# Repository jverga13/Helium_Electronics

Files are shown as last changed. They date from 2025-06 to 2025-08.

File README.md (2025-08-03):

# Helium_Electroincs
This is the Repo where all the libraries and PCB Projects are accumulated.

The paper on which we are basing the majority of the electronics system is available here.

The primary difference between the MIT Paper and our project is that we will be utilizing a camera and LiDAR for navigation, and we are employing "smarter" motors with their built-in motor controllers. 

**[📄Motor Datasheet](https://sdalal1.github.io/assets/pdf/SteadyWin_GIM6010-8_Manual_rev1.pdf)**

**[📄MIT Paper](https://dspace.mit.edu/handle/1721.1/118671)**

**[📄Design Briefing Doc](https://docs.google.com/document/d/1DcKPHw8Bp2Dq9DMruZHhCCMiKNKUiSHHHZJS374k190/edit?usp=sharing)**

**[📄FAQ Document](https://docs.google.com/document/d/1BC8SMq1RszyV6IFdDRlEQbNECk61Qy4wqWS1KBNw0LQ/edit?usp=sharing)**

Images of path below.



**Electronics Logic Flow**
NotebookLM Mind Map (6)

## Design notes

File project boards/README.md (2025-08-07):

# Helium Electronics System Architecture

This directory contains the design files for the custom Printed Circuit Boards (PCBs) that form the core of the robot's electronic system. The architecture is designed to safely manage power and handle the high-speed, real-time communication necessary for dynamic locomotion. The system consists of three primary components:

- **Battery Management System (BMS)**
- **Power Supply Unit (PDB)**
- **SPIne Communication Board**

## Board Interconnection and Function

The diagram below illustrates how the boards connect to each other and to the robot's main computer and motors.

Board Interconnection Diagram

### BMS (Battery Management System)

**Function**: The BMS serves as the robot's primary power source and safety watchdog. We leverage the robust, pre-existing BMS found within a commercial cordless drill battery rather than designing this board ourselves.

**Responsibilities**:
- Provides raw, high-current 24V DC power for the entire system.
- Ensures the safety of the lithium-ion battery pack by managing:
  - Cell balancing
  - Protection against over-charge, over-discharge, short-circuits, and overheating

### PDB (Power Supply Unit)

**Function**: The PDB acts as the central power hub, taking the raw 24V from the battery's BMS and conditioning it for distribution to all other parts of the robot.

**Responsibilities**:
- Provides a high-current 24V rail to power the twelve motor actuators.
- Provides a low-current 1A 5V rail to power the LiDAR (LiDAR is connected to Jetson via Ethernet or USB).
- Includes a pre-charge circuit to safely manage the large inrush of current to the motor controllers' capacitors upon startup.
- Generates a clean, regulated 5V DC "logic power" supply that runs the SPIne board and the Jetson/UP Board (which is connected to the camera via USB).

### SPIne (Communication Board) (July31CommBrd/SPIne-master)

**Function**: The SPIne serves as the real-time "nervous system" of the robot, acting as a high-speed communication bridge between the robot's "brain" (the Jetson/UP Board) and the "muscles" (the motors).

**Responsibilities**:
- Connects to the main computer via a 40-pin header and receives high-level commands (e.g., "move leg 1") over a fast SPI bus.
- Uses two powerful STM32 microcontrollers to translate these simple commands into complex, low-level CAN bus messages.
- Manages four independent, galvanically isolated CAN networks—one for each 3-motor leg. This critical isolation protects the sensitive computer from electrical noise or voltage spikes generated by the motors.
- Maintains the high-frequency (1 kHz+) communication loop required for dynamic balancing and locomotion.

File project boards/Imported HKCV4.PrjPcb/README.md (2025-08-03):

# HKCV4 - [ARCHIVED - REFERENCE ONLY]

**⚠️ IMPORTANT NOTE FOR THE TEAM ⚠️**

This directory, `Imported HKCV4.PrjPcb`, contains the design files for the communication and interface board used in the original MIT research paper. In that project, this board served the role of the high-level computer interface, similar to how we are using a Jetson Nano or UP Board.

**We are NOT using this board in our project.**

These files are archived here for **historical and reference purposes only**. They provide context for how the SPIne and Connector boards were originally connected and controlled.

---

## Original Function (For Context)

The board documented in these files was the central communication hub in the MIT robot. Its primary function was to:

* Act as the main interface board, connecting to a computer like an UP Board.
* Receive high-level commands from the computer over an SPI bus.
* Translate these commands into CAN bus messages for the four 3-DOF legs.
* It is functionally equivalent to what the paper refers to as the **"SPIne"** board.

For our project's active development, please refer to the design files in the `July31CommBrd,` `Best_Connector_board_July`, and `PDB` directories.

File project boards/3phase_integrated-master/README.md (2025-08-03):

## 3-Phase Brushless Motor Controller (V4)

Hardware design files for the Cheetah V4 integrated motor controller.

### Status: Archived ⚠️

This design is a legacy project and is **not in active use**. We have transitioned to using motors with integrated controllers, which makes this external controller board unnecessary for current projects.

The motors we are using are the GIM6010-8-Lite 5Nm 120RPM Max 11Nm 420RPM Robot dog motor with gear box 8:1 and ODrive driver CAN/RS485 Stator 6010 388g. 

### Related Documentation
- **Target Motor Datasheet:** [SteadyWin GIM6010-8 Manual](https://sdalal1.github.io/assets/pdf/SteadyWin_GIM6010-8_Manual_rev1.pdf)
- **Quick Stats GIM Family Motors** [SMC Powers Data Sheet](http://shop.smc-powers.com/GIM6010-8-Lite-Odrive.htlm)
- **Where We Ordered The Motors From** [Amazon](https://www.amazon.com/Planetary-Robotic-Exoskeleton-Control-GIM6010-8/dp/B0DQ7N2M5X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)

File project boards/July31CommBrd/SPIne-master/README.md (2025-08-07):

## Smaller SPIne Communication Board (Cost-Reduced Version)

This directory contains the design files for a modified, cost-reduced version of the main SPIne Communication Board.

### Key Modifications
The primary goal of this version is to lower costs and simplify in-house manufacturing.

- **Reduced Size:** The PCB dimensions have been significantly decreased to lower the cost of fabrication.
- **Fit the OSH Park Rules** The PCB is changed so that it fits OSH parks rules (tracings, distance between components, other errors that occurred  when put into OSH Park Rules)

---
### Original Board Overview

This board is based on the main **SPIne Communication Board**, which acts as the central nervous system for the robot. It processes high-level commands from a host computer (like a Jetson Nano) and manages real-time communication with the motors via CAN bus. It's designed to work with a secondary Connector Board that distributes power and signals.

The core features of the original design include:
- **Dual STM32F446 Microcontrollers** for real-time processing.
- **A 40-pin header** to stack directly onto a host computer.
- **Four independent and galvanically isolated CAN bus channels** for robust motor communication.
- **Onboard power regulation** and isolated DC-DC converters.

---
### Full Documentation

For a complete breakdown of the original board's design, components, and system architecture, please see the full documentation on Notion:

**[📄FAQ Document](https://docs.google.com/document/d/1BTmc7MTexFd-CQ0lYXevFovfLc9VMLDNh9eOhk8kmDs/edit?usp=sharing)**

**[📄 Briefing Doc](https://docs.google.com/document/d/1LLA47OMKxJ5xzOaiPruQMuQE-OeMwa2zv2Psi5w3PYQ/edit?usp=sharing)**

**[📄 Helium Project - SPIne System Details](https://www.notion.so/atombot/The-Helium-Project-1a723e66a3218009b606e8f94d7b40a9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)**

**[📄 Microcontroller Choice Explanation Document](https://docs.google.com/document/d/166toBr8D5q9DAse6OPuDGO7630AuwiWQxv-KNbx1AGk/edit?usp=sharing)**

**[📄 Original Github of SPIne Board](https://github.com/bgkatz/SPIne/tree/master/SPIne_V2)**

image (5)
image (6)

**Concept Tree**

NotebookLM Mind Map (4)

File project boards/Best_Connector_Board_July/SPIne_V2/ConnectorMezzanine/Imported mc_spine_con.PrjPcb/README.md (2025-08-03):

# SPIne Connector and Power Distribution Board

This repository contains the design files for the `mc_spine_con`, a passive connector and power distribution board designed to work with the SPIne V2 communication board for dynamic legged robots.

## Overview

The purpose of this board is to serve as a robust breakout and wiring hub. It takes the bundled power and communication signals from the main SPIne board and distributes them cleanly to the robot's four legs and other peripherals like the remote control receiver and emergency stop. This simplifies the robot's wiring harness, making assembly and maintenance much easier.

This board was designed as part of the research detailed in the [MIT Masters Thesis by Benjamin G. Katz](https://dspace.mit.edu/handle/1721.1/117362).
**I have adjusted this board in the following ways to ensure can iterate on this design quickly through the use of the in-lab Carvera PCB CNC:**
- Replacing the components that are out of circulation
- Changing location of components and traces based on in-lab Carvera rules.

---

## Features

* **Central Input:** A single **20-pin male header** (`SV2`) receives all signals and power from the main SPIne board.
* **Leg Outputs:** Four **4-pin Molex Micro-Fit connectors** (`LEG1` - `LEG4`) provide dedicated power and CAN bus communication to each of the robot's four legs.
* **Remote Control:** A **3-pin header for SBUS** allows for the direct connection of a standard RC radio receiver for low-latency manual control.
* **Safety Interface:** A **2-pin header for an Emergency Stop (ESTOP)** provides a connection point for a critical safety cutoff switch.
* **Power Taps:** Five **8-pin Molex Micro-Fit headers** (`P$1`) are available for distributing power to other subsystems.
* **Mounting:** Four **mounting holes** (`MH1` - `MH4`) allow the board to be securely fastened to the robot chassis.
* **Construction:** Simple and robust **2-layer PCB** design, suitable for manufacturing with desktop PCB makers or professional fabrication houses.

---

## Repository Contents

* **/AltiumProject/**: Contains the source Altium Designer project files, including:
    * `mc_spine_con.PcbDoc` - The PCB layout file.
    * `mc_spine_con.SchDoc` - The schematic file.
* **/Gerber/**: Manufacturing files (Gerbers) for producing the PCB.
* **/BOM/**: The Bill of Materials (`.csv`) listing all required components and their part numbers.
* `README.md`: This file.

---

## Integration

This board is designed to be the interface layer between the main SPIne V2 board and the robot's hardware.

1.  The **female 20-pin connector** (`SV1`, Harwin `M20-7822046`) on the main SPIne board plugs directly into the **male 20-pin header** (`SV2`, Harwin `M20-9992046`) on this connector board.
2.  The `LEG` ports connect to the motor controllers in each leg.
3.  The `SBUS` and `ESTOP` ports connect to the respective external hardware.
4.  The main power for the system is supplied to the SPIne board, which then passes it through to this board for distribution.

---

## License

This project is licensed under the MIT License. See the `LICENSE` file for details.

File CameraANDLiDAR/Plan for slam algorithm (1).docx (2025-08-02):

### ✅ Most Relevant Tutorials

1. RGB-D Handheld Mapping
  - Why: Your RealSense D435i is an RGB-D camera, which is directly supported by this tutorial.
  - Use Case: This will help you understand how to perform SLAM using only the D435i.
2. Setup RTAB-Map on Your Robot!
  - Why: Since you’re using both an RGB-D camera and a LiDAR, this tutorial helps integrate multiple sensors.
  - Use Case: Essential if you're mounting these sensors on a robot and want to combine odometry, visual data, and LiDAR.
3. Advanced Parameter Tuning
  - Why: When combining RGB-D and LiDAR, performance tuning is important for accuracy and efficiency.
  - Use Case: Optimize SLAM performance once basic setup is complete.

### 🚧 Potentially Useful (Depending on Deployment)

4. Remote Mapping
  - Why: Useful if the compute-heavy SLAM processing is done on a separate computer.
  - Use Case: Consider this if your robot is lightweight and offloads processing.
5. Stereo Outdoor Mapping / Navigation
  - Why: Not directly applicable since you're not using stereo, but helpful if you're working in outdoor environments and want ideas on sensor fusion/navigation.
  - Use Case: You can extract concepts related to environment challenges and trajectory planning.

### ❌ Not Directly Applicable

- Stereo Handheld Mapping
- Mapping and Navigation with Turtlebot
- Tango ROS Streamer
- Wifi Signal Strength Mapping

These are either tied to specific hardware (e.g., stereo cameras, Turtlebot, Tango) or niche use cases not related to your current SLAM goal.

### Suggested Learning Path

1. Start with "RGB-D Handheld Mapping" to understand how to get RTAB-Map working with the D435i.
2. Then go to "Setup RTAB-Map on Your Robot!" to integrate LiDAR and configure multi-sensor input.
3. Use "Advanced Parameter Tuning" to refine performance and improve map quality.
4. (Optional) Use "Remote Mapping" if you're offloading compute tasks.

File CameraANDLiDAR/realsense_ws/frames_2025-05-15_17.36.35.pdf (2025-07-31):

view_frames Result

Recorded at time: 1747344995.4423993

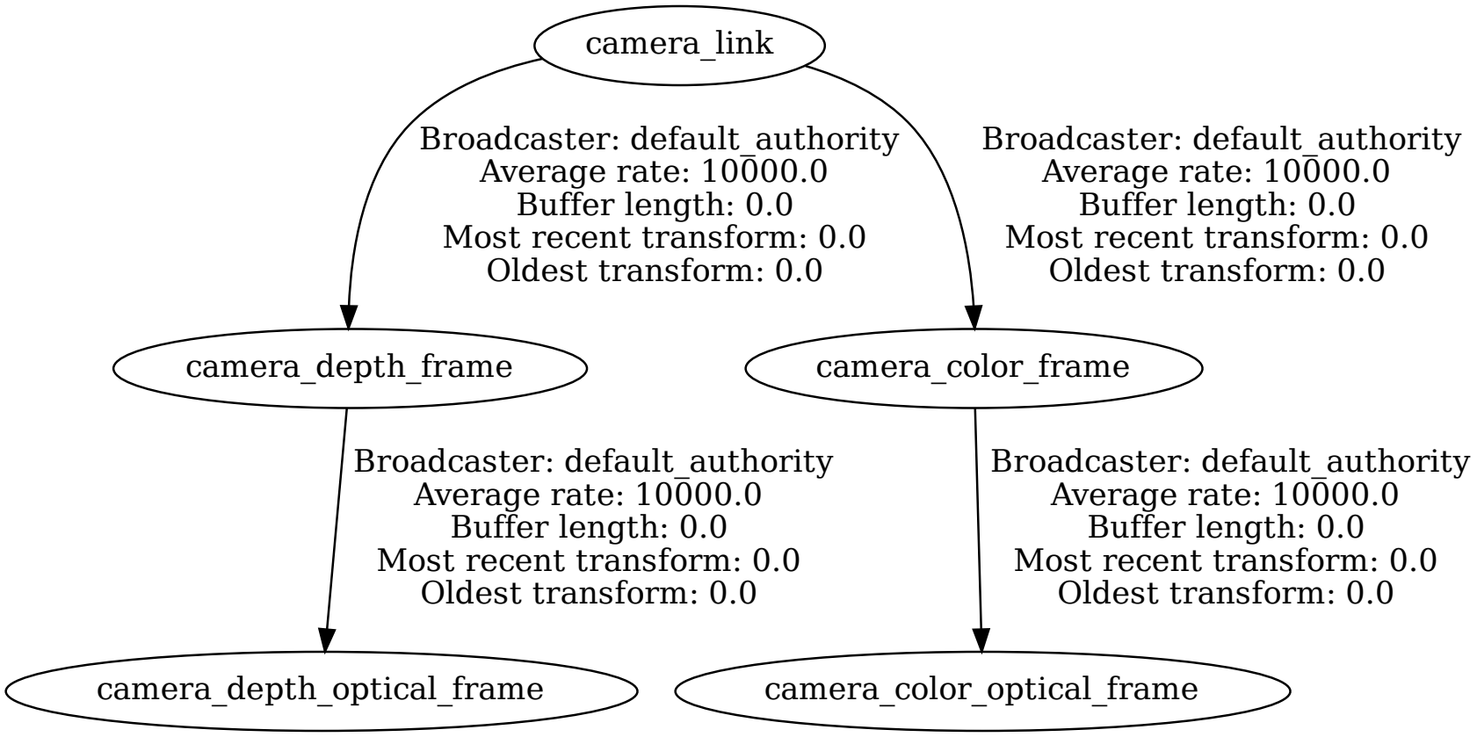
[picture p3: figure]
camera_link; camera_depth_frame; Broadcaster: default_authority Average rate: 10000.0 Buffer length: 0.0 Most recent transform: 0.0 Oldest transform: 0.0; camera_color_frame; camera_depth_optical_frame; camera_color_optical_frame

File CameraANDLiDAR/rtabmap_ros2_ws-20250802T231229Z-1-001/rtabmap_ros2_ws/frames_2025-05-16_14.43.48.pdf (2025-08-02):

view_frames Result

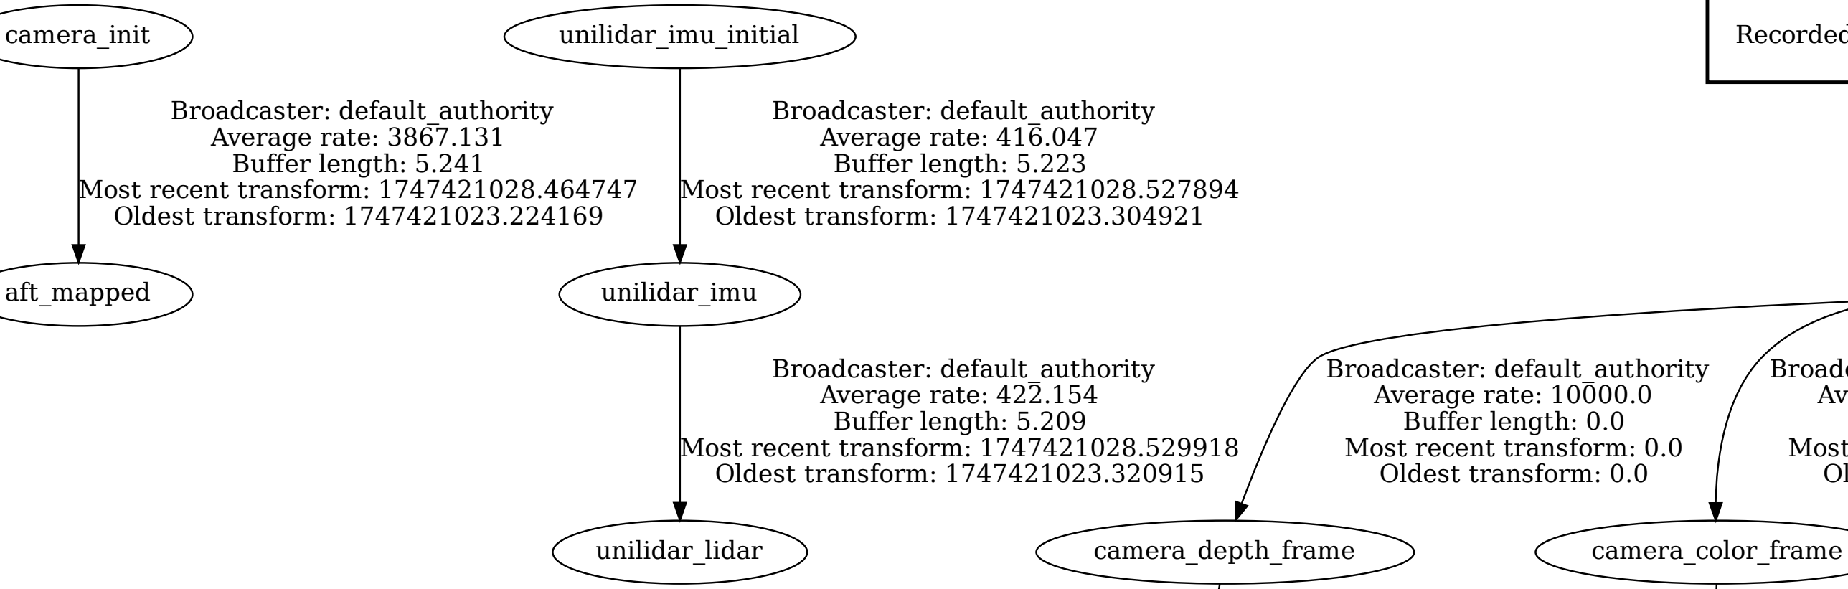
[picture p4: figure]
camera_init; aft_mapped; Broadcaster: default_authority Average rate: 3867.131 Buffer length: 5.241 Most recent transform: 1747421028.464747 Oldest transform: 1747421023.224169; unilidar_imu_initial; unilidar_imu; Broadcaster: default_authority Average rate: 416.047 Buffer length: 5.223 Most recent transform: 1747421028.527894 Oldest transform: 1747421023.304921; unilidar_lidar; Broadcaster: default_authority Average rate: 422.154 Buffer length: 5.209 Most recent transform: 1747421028.529918 Oldest transform: 1747421023.320915; camera_depth_frame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

Recorded at time: 1747421028.5395234

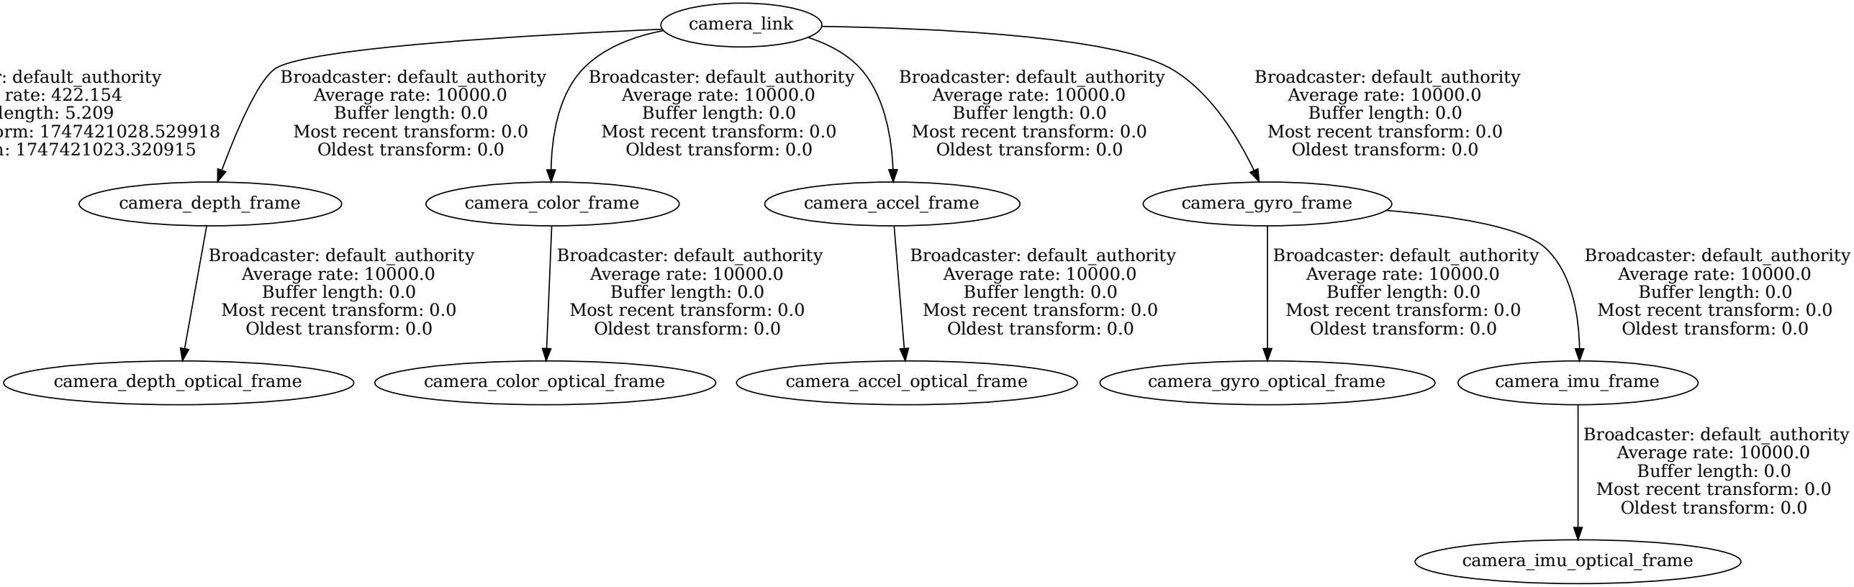
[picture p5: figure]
camera_link; Broadcaster: default_authority Average rate: 10000.0 Buffer length: 0.0 Most recent transform: 0.0 Oldest transform: 0.0; camera_accel_frame; camera_gyro_frame; camera_depth_optical_frame; camera_color_optical_frame; camera_accel_optical_frame; camera_gyro_optical_frame; camera_imu_frame; camera_imu_optical_frame

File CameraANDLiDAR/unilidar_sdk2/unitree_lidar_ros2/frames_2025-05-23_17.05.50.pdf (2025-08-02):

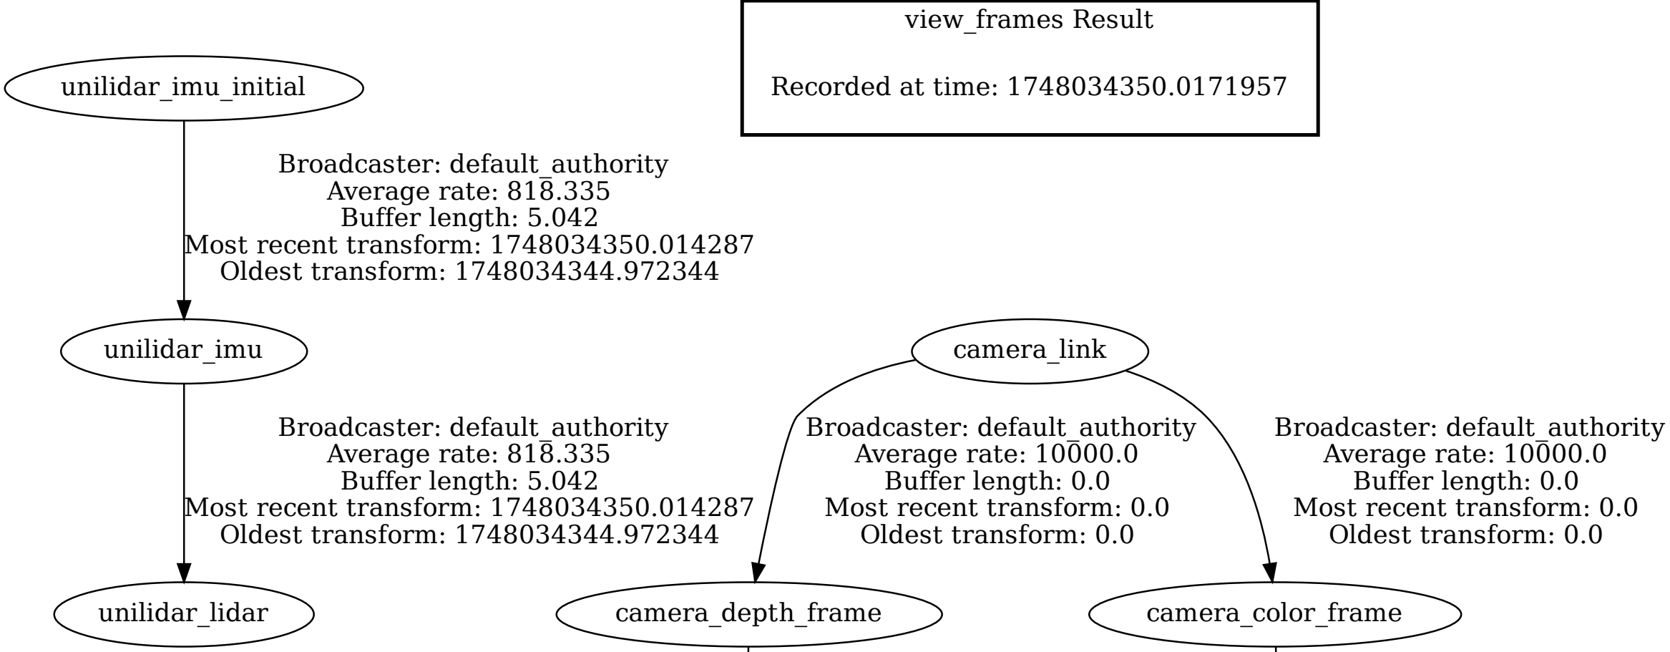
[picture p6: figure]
view_frames Result; unilidar_imu_initial; unilidar_imu; Broadcaster: default_authority Average rate: 818.335 Buffer length: 5.042 Most recent transform: 1748034350.014287 Oldest transform: 1748034344.972344; unilidar_lidar; camera_link; camera_depth_frame; Broadcaster: default_authority Average rate: 10000.0 Buffer length: 0.0 Most recent transform: 0.0 Oldest transform: 0.0; camera_color_frame; Recorded at time: 1748034350.0171957
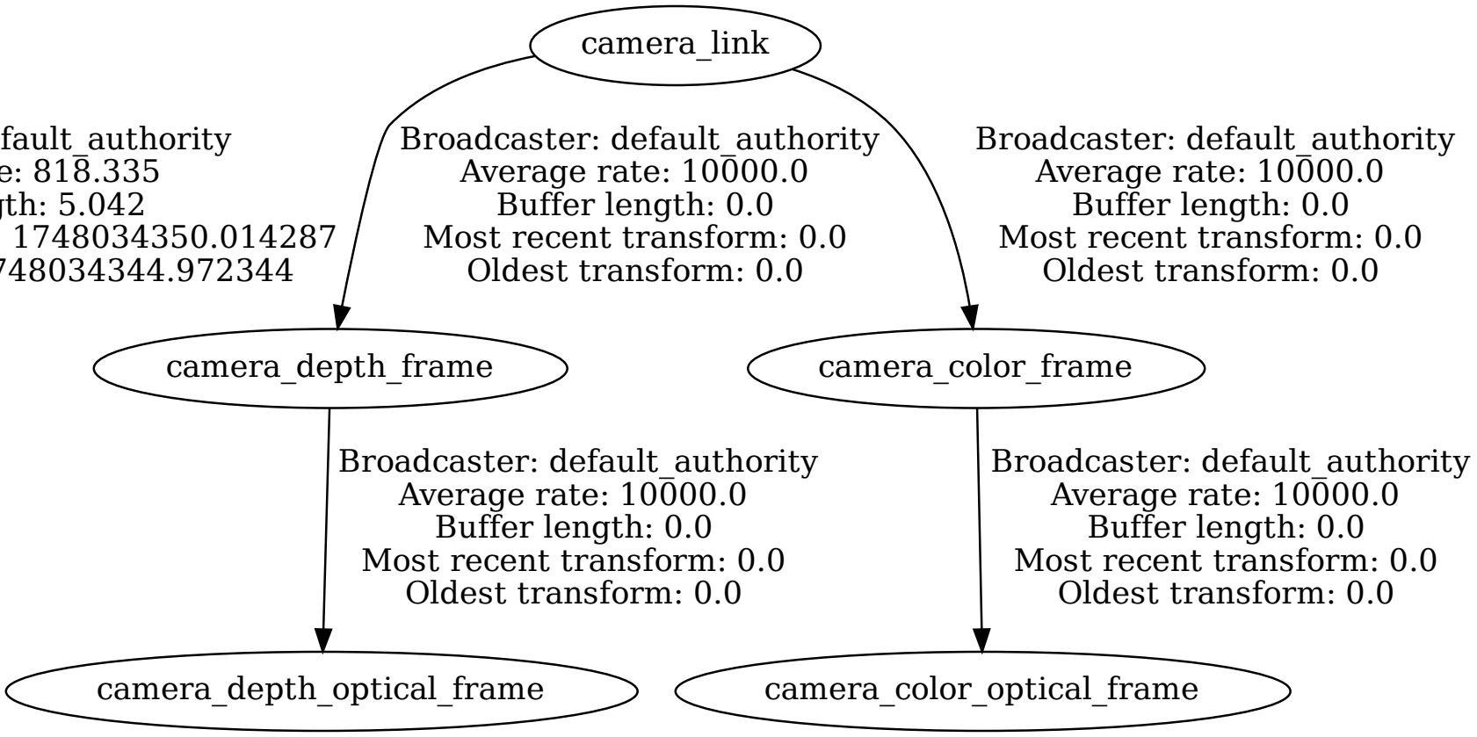
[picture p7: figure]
camera_depth_optical_frame; Broadcaster: default_authority Average rate: 10000.0 Buffer length: 0.0 Most recent transform: 0.0 Oldest transform: 0.0; camera_color_optical_frame

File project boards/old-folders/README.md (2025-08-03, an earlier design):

# [ARCHIVED] - Old and Deprecated Designs

**❗ Important Notice ❗**

This directory contains a collection of old, experimental, and deprecated design files. The contents of this folder are **not for current use**.

---

## Purpose of this Directory

The designs in this folder are kept for a few key reasons:

* **Historical Record:** They show the evolution and progression of our design process.
* **Reference:** There may be specific ideas, component footprints, or routing techniques in these old files that could be useful for reference in future projects.
* **Learning:** They serve as a record of what worked and, more importantly, what didn't.

Please **do not** use any of the projects in this directory as a starting point for new work. They may be incomplete, contain errors, or use outdated components.

For all active and current projects, please refer to the main project directories.

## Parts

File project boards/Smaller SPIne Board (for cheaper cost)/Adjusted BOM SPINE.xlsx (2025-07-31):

# of Components | Value | Package | Part | MFG Part Number | Digikey Number | Substitute Part Numbler | Function | Ordered (Y/N)
1 |  | 43045-0400 (https://www.digikey.com/en/products/detail/molex/0430450400/252527?msockid=1619689cf2a2642d35897d04f3dc6515) | DC_IN | ‎0430450400‎ | ‎WM1814-ND‎ | 430450411 (https://www.digikey.com/en/products/detail/molex/0430450411/252545) | Main DC Power Input: Receives power from the robot's primary battery.
1 |  | MA20-1L (https://www.digikey.com/en/products/detail/harwin-inc/M20-7822046/3727872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) | SV1 | ‎M20-7822046‎ | ‎952-1905-ND‎ |  | 20-pin Connector to Connector Board: Interface that passes power and communication signals to the mc_spine_con breakout board.
4 | 120 | R0402 (https://www.digikey.com/en/products/detail/te-connectivity-passive-product/CRGCQ0603F120R/8576279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) | R3, R5, R6, R7 | ‎CRGCQ0603F120R‎ | ‎A129677CT-ND‎ |  | CAN Bus Termination Resistors: 120-ohm resistors placed at the physical ends of the CAN bus to prevent signal reflections and ensure reliable communication.
1 | DNP | R0402 (https://www.digikey.com/en/products/detail/yageo/RC0402JR-070RL/726406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) | BYP | RC0402JR-070RL |  | RC0402JR-070RP (https://www.digikey.com/en/products/detail/yageo/RC0402JR-070RP/4935394) | Bypass Resistor (Do Not Populate): A placeholder on the PCB for testing or optional configurations; not installed in the final assembly. |  | <-- don't order this now
20 | .1 uF | C0603K (https://www.digikey.com/en/products/detail/kemet/C0603C104M5RACTU/2199782) | C1, C8, C12, C14, C16, C18, C19, C20, C21, C22, C23, C24, C4, C5, C6, C25, C27, C29, C31, C32 | ‎C0603C104M5RACTU‎ | ‎399-7845-1-ND‎ |  | Decoupling/Filtering Capacitors: Placed near ICs to filter high-frequency noise from power supply lines and provide a stable voltage for digital components.
8 | 1uF | C0603 (https://www.digikey.com/en/products/detail/taiyo-yuden/UMK107AB7105KA-T/3660085) | C7, C41, C11, C13, C15, C17, C3, C10 | ‎UMK107AB7105KA-T‎ | ‎587-3247-1-ND‎ |  | Decoupling/Filtering Capacitors: Mid-range frequency filtering for power stability.
1 | 10 uF | C0805K (https://www.digikey.com/en/products/detail/murata-electronics/GRM188R61E106MA73D/3900497) | C30 | ‎GRM188R61E106MA73D‎ | ‎490-7202-1-ND‎ |  | Bulk Decoupling Capacitor: Larger capacitor to handle lower-frequency fluctuations and sudden current demands from the circuit.
2 | 4.7 uF | C0603 (https://www.digikey.com/en/products/detail/samsung-electro-mechanics/CL10A475MQ8NNNC/3887565) | C2, C9 | ‎CL10A475MQ8NNNC‎ | ‎1276-1907-1-ND‎ |  | Decoupling/Filtering Capacitors: Additional filtering for power stability.
5 | 47 uF | C1206K (https://www.digikey.com/en/products/detail/murata-electronics/GRT32EC81C476KE13L/5417195) | C28, C33, C34, C35, C36 | ‎GRM32EC81C476KE15K‎ | ‎490-16309-1-ND‎ | GRT32EC81C476KE13L (https://www.digikey.com/en/products/detail/murata-electronics/GRT32EC81C476KE13L/5417195) | Bulk Decoupling Capacitors: Provides a substantial local energy reserve to stabilize voltage during large, rapid changes in current draw.
2 | 600r | 603 (https://www.digikey.com/en/products/detail/pulse-electronics/PE-0603FB601ST/5050541) | CHOKE, CHOKE1 | ‎PE-0603FB601ST‎ | ‎553-2384-1-ND‎ |  | Power Supply Filtering Chokes: Inductors that form an LC filter with capacitors to block high-frequency noise from entering sensitive parts of the circuit.
2 | 200 | R0603 (https://www.digikey.com/en/products/detail/yageo/RC0603JR-07200RL/726737) | R4, R22 | ‎RC0603JR-07200RL‎ | ‎311-200GRCT-ND‎ |  | General Purpose Resistors: Used for tasks like current limiting or as part of pull-up/pull-down circuits to ensure signals are in a defined state.
1 | 74AHC1G14DCK | SC70-5 (https://www.digikey.com/en/products/detail/texas-instruments/SN74AHC1G14DCKR/373809) | IC1 | SN74AHC1G14DCKR | 296-8748-1-ND |  | Logic Gate (Schmitt-Trigger Inverter): Inverts a digital signal and provides clean, sharp output transitions, even from noisy or slow-changing inputs.
2 | BM07B-SRSS-TB | BM07B-SRSS-TB (https://www.digikey.com/en/products/detail/jst-sales-america-inc/BM07B-SRSS-TB/926699) | PROG, PROG1 | ‎BM07B-SRSS-TB(LF)(SN)‎ | ‎455-1793-1-ND‎ |  | Programming/Debug Ports for MCUs: Allows direct connection (e.g., SWD/JTAG) for flashing firmware and real-time debugging of the microcontrollers.
2 | CSTCE | CSTCE (https://www.digikey.com/en/products/detail/murata-electronics/CSTNE8M00GH5C000R0/8747742) | XT1, XT2 | CSTNE8M00GH5C000R0‎ | ‎490-17961-1-ND‎ |  | Crystal Resonators for MCUs: Provides a precise and stable 8 MHz clock signal, which is essential for the microcontrollers to execute instructions and time communications accurately.
2 | LED_RED | LED-0603 (https://www.digikey.com/en/products/detail/liteon/LTST-C191KRKT/386837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) | LED2, LED4 | ‎LTST-C191KRKT‎ | ‎160-1447-1-ND‎ |  | Status Indicator LEDs: Provides visual feedback on the board's status, such as power on, communication activity, or error codes.
1 | LM1117 | SOT-223 (https://www.digikey.com/en/products/detail/texas-instruments/LM1117MPX-3-3-NOPB/366733) | VR1 | LM1117MPX-3.3/NOPB | LM1117MPX-3.3/NOPBCT-ND |  | 3.3V Linear Voltage Regulator: Converts the main input voltage to a stable 3.3V to power the microcontrollers and other digital logic ICs.
4 | ‎MCP2562-E/SN‎ | SO08 (https://www.digikey.com/en/products/detail/microchip-technology/MCP2562-E-SN/4079967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) | U$4, U$5, U$6, U$7 | ‎MCP2562-E/SN‎ | ‎MCP2562-E/SN-ND‎ |  | CAN Bus Transceivers: Converts logic-level signals (TX/RX) from the MCUs into the differential signals required for robust physical communication over the CAN bus.
4 | SI8621EC-B-IS | SO08 (https://www.digikey.com/en/products/detail/skyworks-solutions-inc/SI8621EC-B-IS/2623314) | U$8, U$9, U$10, U$11 | SI8621EC-B-IS | 336-2066-5-ND | ADUM121N1BRZ (https://www.digikey.com/en/products/detail/analog-devices-inc/ADUM121N1BRZ/5957960) | Digital Isolators for CAN Bus: Provides galvanic isolation to protect the sensitive MCUs from electrical noise and voltage spikes on the CAN bus network.
2 | STM32F446RET6 | TQFP64 (https://www.digikey.com/en/products/detail/stmicroelectronics/STM32F446RET6/5175962) | U$1, U$3 | ‎STM32F446RET6‎ | ‎497-15376-ND‎ |  | Main Microcontrollers: The "brains" of the board; they process commands from the host computer and manage communication with the robot's leg motors via CAN bus.
4 | ‎CRE1S0505S3C‎ | 4SIL (https://www.digikey.com/en/products/detail/murata-power-solutions-inc/CRE1S0505S3C/6056051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) | DC1, DC2, DC3, DC4 | ‎CRE1S0505S3C‎ | ‎811-3195-ND‎ | TMR 1-0511 (https://www.digikey.com/en/products/detail/traco-power/TMR-1-0511/9383368) | Isolated DC-DC Converters: Provides isolated 5V power, likely for the CAN bus transceivers, to prevent ground loops and protect the main power supply.
4 | 17mm hex standoff |  |  | ‎971170151‎ (https://www.digikey.com/en/products/detail/w%C3%BCrth-elektronik/971170151/6174643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) | ‎732-10424-ND‎ |  | Mechanical Standoff: Hardware for physically mounting the PCB and maintaining proper spacing within the robot's chassis.
4 | 11mm hex standoff |  |  | ‎M2106-2545-AL‎ (https://www.digikey.com/en/products/detail/raf-electronic-hardware/M2106-2545-AL/7681435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) | ‎1772-2024-ND‎ |  | Mechanical Standoff: Hardware for physically mounting the PCB and maintaining proper spacing within the robot's chassis.
1 | 40 pin |  |  | SSQ-120-02-T-D (https://www.digikey.com/en/products/detail/samtec-inc/SSQ-120-02-T-D/1111244) | SAM1193-20-ND |  | 40-pin Connector to Host Computer: Main data/control interface to the high-level computer (e.g., UP Board), carrying SPI, I2C, UART, and power signals.
*Can find & are available | *Can't find / aren't available | *Found a substitute
First Round Order Sheet
# of Components to Order (for backup & future boards and price for buying in bulk) | # Components needed on Board | MFG Part Number | Price | Component Type
30 | 20 | C0603K: ‎C0603C104M5RACTU‎ (https://www.digikey.com/en/products/detail/kemet/C0603C104M5RACTU/2199782) | $5.73 | Capacitor
20 | 8 | C0603: UMK107AB7105KA-T (https://www.digikey.com/en/products/detail/taiyo-yuden/UMK107AB7105KA-T/3660085) | $0.62 | Capacitor
10 | 1 | C0805K: ‎GRM188R61E106MA73D‎ (https://www.digikey.com/en/products/detail/murata-electronics/GRM188R61E106MA73D/3900497) | $1.50 | Capacitor
10 | 2 | C0603: ‎CL10A475MQ8NNNC‎ (https://www.digikey.com/en/products/detail/samsung-electro-mechanics/CL10A475MQ8NNNC/3887565) | $0.35 | Capacitor
10 | 5 | GRT32EC81C476KE13L (https://www.digikey.com/en/products/detail/murata-electronics/GRT32EC81C476KE13L/5417195) | $5.44 | Capacitor
10 | 4 | R0402: ‎CRGCQ0603F120R‎ (https://www.digikey.com/en/products/detail/te-connectivity-passive-product/CRGCQ0603F120R/8576279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) | $0.28 | Resistor
10 | 2 | 603: ‎PE-0603FB601ST‎ (https://www.digikey.com/en/products/detail/pulse-electronics/PE-0603FB601ST/5050541) | $0.33 | Inductor
10 | 2 | R0603: ‎RC0603JR-07200RL‎ (https://www.digikey.com/en/products/detail/yageo/RC0603JR-07200RL/726737) | $0.08 | Resistor
1 | 1 | MA20-1L: ‎M20-7822046‎ (https://www.digikey.com/en/products/detail/harwin-inc/M20-7822046/3727872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) | $2.20 | Connector
1 | 1 | SSQ-120-02-T-D (https://www.digikey.com/en/products/detail/samtec-inc/SSQ-120-02-T-D/1111244) | $3.91 | Connector
2 | 2 | STM32F446RET6 (https://www.digikey.com/en/products/detail/stmicroelectronics/STM32F446RET6/5175962) | $17.22 | STM

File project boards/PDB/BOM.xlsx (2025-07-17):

QTY | Value | Device | Parts | Digikey Part Number | Other Distributor
2 |  | DIODE-SMB | D4, D6 | 497-16321-1-ND
2 |  | HEADER_POS4_43045-0401 | 5V_OUT, 12V_OUT | ‎WM1814-ND‎
2 | .1uF 50V | C-USC0603K | C4, C17 | 399-7845-1-ND
4 | 100 | R-US_R0402 | R3, R11, R12, R13 | 311-100JRCT-ND
10 | 10k | R-US_R0402 | R1, R2, R4, R5, R6, R8, R9, R14, R15, R16 | 311-10.0KLRCT-ND
4 | 10uF 25v | C-USC0603K | C1, C3, C7, C8 | 490-7202-1-ND
8 | 10uF 50v | C-USC1206K | C9, C11, C12, C13, C16, C18, C19, C20 | 587-3248-1-ND
2 | 1uF 50v | C-USC0603K | C2, C6 | 587-3247-1-ND
2 | 2-PINM80_H | 2-PINM80_H | U$13, U$14 | 952-1076-5-ND
2 | 20k | R-US_R0402 | R7, R10 | 311-20.0KLRCT-ND
7 | 220uF 35v | CPOL-USE3.5-8 | C5, C10, C14, C15, C21, C22, C23 | UVY1V221MPD-ND
2 | 470nH | CPOL-USE3.5-8 | L1, L2 | 490-10596-1-ND
2 | 51 | CPOL-USE3.5-8 | R17, R18 | RHM51DCT-ND
2 | 78L12SMD | CPOL-USE3.5-8 | IC1, IC2 | ‎LM78L12ACM/NOPB-ND‎
2 | LMC7211BIM5/NOPB | LMC7211BIM5/NOPB | U3, U4 | ‎LMC7211BIM5/NOPBCT-ND‎
5 | N-FETPOWER_SO8 | N-FETPOWER_SO8 | Q1, Q2, Q3, Q4, Q5 | ‎TPW1R306PLL1QCT-ND‎
1 | PDQ30-Q24-S5-D | PDQ30-Q24-S5-D | 5v | 102-3891-ND
1 | PDQ30-Q24-S12-D | PDQ30-Q24-S12-D | 12v | 102-3892-ND
2 | 2 | RESISTOR D2PAK | R_L, R_M | ‎PWR263S-35-2R00J-ND‎
2 | QFIT |  | "+, -"
4 | XT30PW-F |  | U$3, U$8, U$9, U$10 |  | https://www.tme.com/us/en-us/details/xt30pw-f/dc-power-connectors/amass/
4 |  | DIODE-DO214AC | D1, D2, D3, D5 | ‎SMAJ12ALFCT-ND‎
2 |  | TMS6T3B1M1QE | Power Switches | 450-2071-ND
2 |  | M80-8980205 | Power Switch Connectors | 952-1182-ND

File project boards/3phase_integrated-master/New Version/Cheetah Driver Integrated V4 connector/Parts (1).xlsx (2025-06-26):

Supplied Parts
Qty Per Board | Value | Device | Package | Parts | MFG Part | 56
1 | DRV8323RH | DRV8323RH | QFN50P700X700X90-49N | U$1 | ‎DRV8323RSRGZT‎
2 | G | LED0603 | LED-0603 | LED1, LED2 | LTST-C191KRKT‎
1 | 3.3V 500 mA LDO | LDFM | DFN6-3X3 | LDFM33PUR | ‎LDFM33PUR‎
1 | MA700 | MA700 | QFN16 | U$11 | ‎MA700GQ-Z‎
1 | MCP2542 | MCP2542 | TDFN | U$6 | ‎MCP2542FDT-H/MNY‎
1 | SM07B-SRSS-TB | SM07B-SRSS-TB | SM07B-SRSS-TB | PROG | ‎SM07B-SRSS-TB(LF)(SN)‎
1 | STM32F446RET6 | STM32F446RET6 | TQFP64 | U$3 | ‎STM32F446RET6‎
6 | 60V | MOSFET | Power SO8 | Q1, Q2, Q3, Q4, Q5, Q6 | ‎TPH2R506PL,L1Q‎
9 | 10 uF 50v | C-USC1206K | C1206K | C1, C8, C11, C12, C13, C14, C15, C16, C17, C21, C22, C23, C24, C25, C26, C28, C29 | GRT31CR61H106ME01L
1 | 22uH 500 mA | SDR0302 | SDR0302 | L1 | ‎NRH3012T220MN‎
2 | 0.001 | R-US_R1210 | R1210 | R6, R7 | ‎PMR25HZPFV1L00‎
1 | 600r | INDUCTOR0603 | 603 | CHOKE | ‎PE-0603FB601ST‎
1 | 8 Mhz Ceramic Resonator | CSTCE | CSTCE | XT1 | ‎CSTNE8M00GH5L000R0‎
1 | 500 mA 60v | DIODE-SOD123 | SOD123 | D1 | ‎MBR0580S1-7‎
8 | .1 uF 10v X5R/X7R | C-USC0402K | C0402K | C18, C27, C31, C32, C33, C34, C41, VREFCAP | ‎CL05A104MP5NNNC
2 | .1 uF 50v X5R/X7R | C-USC0603K | C0603K | C2, C4 | ‎CC0603JRX7R9BB104‎
3 | 1 uF 10v X5R/X7R | C-USC0402K | C0402K | C7, C10, MC1 | ‎CL05A105MP5NNNC‎
1 | 1 uF 50v X5R/X7R | C-USC0603K | C0603K | C6 | ‎CL10A105KB8NNNC‎
4 | 10k 1% | R-US_R0402 | R0402 | R2, R3, R4 R27 | ‎RT0402DRE0710KL‎
1 | 150k 1% | R-US_R0402 | R0402 | R26 | ‎RMCF0402FT150K‎
2 | 200 5% | R-US_R0402 | R0402 | R5, R22 | ‎RC0402JR-07200RL‎
3 | 22 uF 10v X5R/X7R | C-USC0603K | C0603K | C3, C19, C20 | ‎CL10A226MPCNUBE‎
1 | 4.7 uF 10v X5R/X7R | C-USC0402K | C0402K | C9 | ‎GRM155R60J475ME87D‎
1 | 47 nF 50v X5R/X7R | C-USC0402K | C0402K | C5 | ‎CGA2B3X7R1H473M050BD‎
1 | 54.9k 1% | R-US_R0402 | R0402 | R1 | ‎RC0402FR-0754K9L‎

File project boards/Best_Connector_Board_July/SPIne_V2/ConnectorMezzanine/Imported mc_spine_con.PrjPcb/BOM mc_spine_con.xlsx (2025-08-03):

# of Components | Value | Package | Part | MFG Part Number | Digikey Number | Substitute Part Numbler | Description | Function | Ordered (Y/N)
6 |  |  |  | M80-8430342 (https://www.digikey.com/en/products/detail/harwin-inc/M80-8430342/3924159?s=N4IgTCBcDaILIA4AMBaBAWAzEz6IF0BfIA) | 952-2944-ND |  |  | Connection headers for the wires that connect to the Motors/ESTOP/SBUS
6 |  |  |  | S8111-46R | 952-1578-1-ND | S8121-46R (https://www.digikey.com/en/products/detail/harwin-inc/S8121-46R/2281824?s=N4IgTCBcDaIMoA4CMYkFoAsA2ASiAugL5A) |  | Clips for the wires that connect to the Motors/ESTOP/SBUS
1 |  | MA20-1L (https://www.digikey.com/en/products/detail/harwin-inc/M20-9992046/3727869) | SV2 | M20-9992046 (https://www.digikey.com/en/products/detail/harwin-inc/M20-9992046/3727869) | 952-1902-ND |  | SV2 | 20-pin Connector to Main SPIne Board
*Can find & are available | *Can't find / aren't available | *Found a substitute
Components Order List
# of Components to Order (for backup & future boards and price for buying in bulk) | # Components needed on Board | MFG Part Number | Price
8 | 6 | M80-8430342 (https://www.digikey.com/en/products/detail/harwin-inc/M80-8430342/3924159?s=N4IgTCBcDaILIA4AMBaBAWAzEz6IF0BfIA) | $13.50
10 | 6 | S8121-46R (https://www.digikey.com/en/products/detail/harwin-inc/S8121-46R/2281824?s=N4IgTCBcDaIMoA4CMYkFoAsA2ASiAugL5A) | $2.24
2 | 1 | M20-9992046 (https://www.digikey.com/en/products/detail/harwin-inc/M20-9992046/3727869) | $1.38

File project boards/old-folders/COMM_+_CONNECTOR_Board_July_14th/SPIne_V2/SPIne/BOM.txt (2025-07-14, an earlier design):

Partlist exported from C:/Users/ben/Documents/eagle/mini cheetah spine/mc_spine/spine.sch at 10/16/2019 5:14 PM

Qty Value         Device                 Package       Parts                                                    Description                                                                         MATERIAL MF MPN OC_FARNELL OC_NEWARK SPICEPREFIX
1                 HEADER_POS4_43045-0401 43045-0400    DC_IN                                                    Molex - Micro-Fit 3.0 Series connector,  3.00mm (0.118") pitch header, 4 positions.
1                 MA20-1L                MA20-1L       SV1                                                      PIN HEADER                                                                                          unknown    unknown
4                 R-US_R0402             R0402         R3, R5, R6, R7                                           RESISTOR, American symbol
1                 R-US_R0402             R0402         BYP                                                      RESISTOR, American symbol                                                                                                R
12  .1 uF         C-USC0603K             C0603K        C1, C8, C12, C14, C16, C18, C19, C20, C21, C22, C23, C24 CAPACITOR, American symbol
2   1 uF          C-USC0603              C0603         C7, C41                                                  CAPACITOR, American symbol
4   1 uF          C-USC0603K             C0603K        C11, C13, C15, C17                                       CAPACITOR, American symbol
8   100nF         C-USC0603              C0603         C4, C5, C6, C25, C27, C29, C31, C32                      CAPACITOR, American symbol
1   10uF          C-USC0805K             C0805K        C30                                                      CAPACITOR, American symbol
2   1uF           C-USC0603              C0603         C3, C10                                                  CAPACITOR, American symbol                                                                                                          
2   4.7           C-USC0603              C0603         C2, C9                                                   CAPACITOR, American symbol                                                                                                          
5   47 uF         C-USC1206K             C1206K        C28, C33, C34, C35, C36                                  CAPACITOR, American symbol
2   600r          INDUCTOR0603           0603          CHOKE, CHOKE1                                            Inductors                                                                                                                           
2   70            R-US_R0603             R0603         R4, R22                                                  RESISTOR, American symbol                                                                                                           
1   74AHC1G14DCK  74AHC1G14DCK           SC70-5        IC1                                                      Single Schmitt-Trigger Inverter Gate                                                                                                
2   BM07B-SRSS-TB BM07B-SRSS-TB          BM07B-SRSS-TB PROG, PROG1                                              Disconnectable Crimp style connector, 1.0mm pitch7 contacts                                                                         
2   CSTCE         CSTCE                  CSTCE         XT1, XT2                                                                                                                                                                                     
2   G             LED0603                LED-0603      LED2, LED4                                               LEDs
1   LM1117        LM1117                 SOT-223       VR1
4   MCP2561       MCP2561                SO08          U$4, U$5, U$6, U$7
4   SI8410        SI8410                 SO08          U$8, U$9, U$10, U$11
2   STM32F446RET6 STM32F446RET6          TQFP64        U$1, U$3                                                 ARM DSP Chip used on the WAV Trigger board.
1   UP_BOARD      UP_BOARD               UP_BOARD      U$2
4   VA-1224S      VA-1224S               4SIL          DC1, DC2, DC3, DC4                                       DC DC Converter Single Output, 1 Watt                                                               unknown    unknown

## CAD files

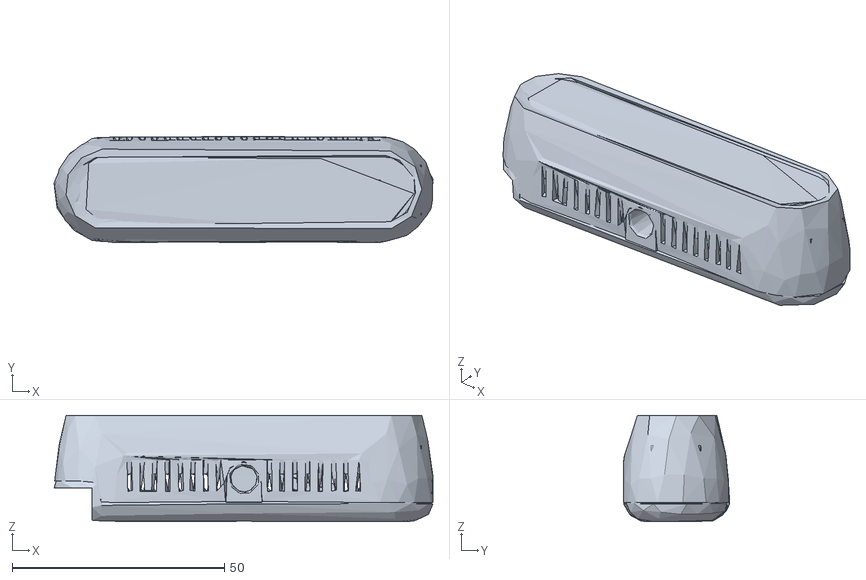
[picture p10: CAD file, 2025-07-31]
CameraANDLiDAR/tutorials-20250802T231226Z-1-001/tutorials/librealsense/common/res/sources/D435.obj
89.2 x 25.0 x 25.0

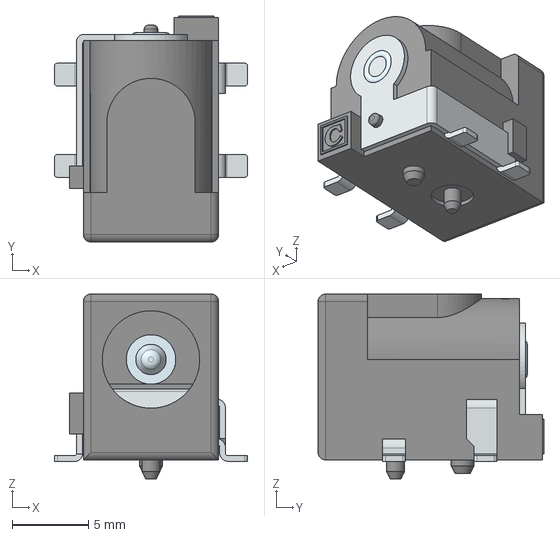
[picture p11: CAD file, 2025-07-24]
project boards/PDB/Imported PDB.PrjPcb/LiDAR power surface mount plug.stp
12.7 x 14.8 x 12.2 mm

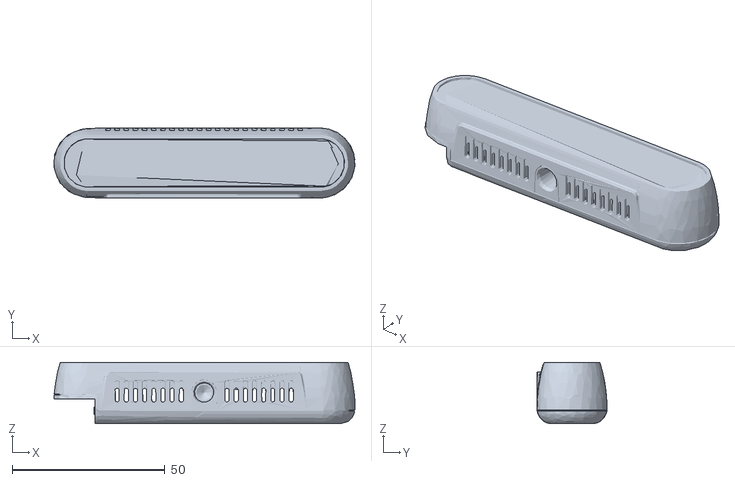
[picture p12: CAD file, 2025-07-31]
CameraANDLiDAR/tutorials-20250802T231226Z-1-001/tutorials/librealsense/common/res/sources/D415.obj
98.6 x 23.0 x 20.0

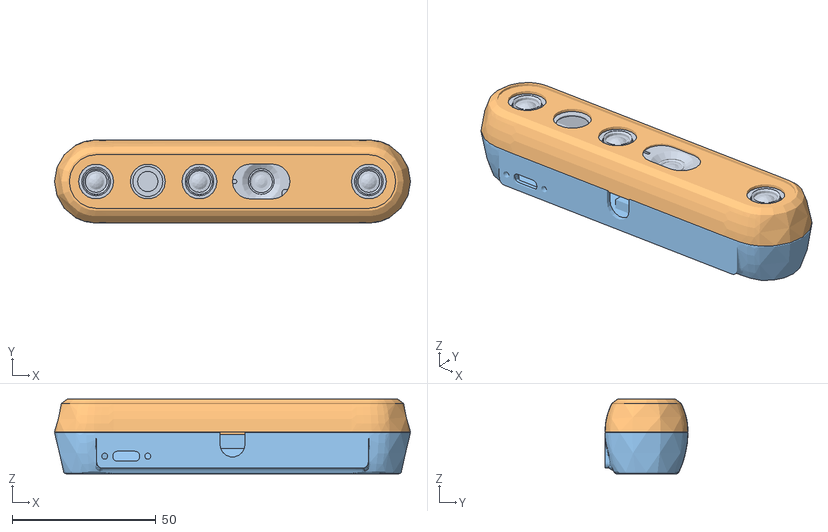
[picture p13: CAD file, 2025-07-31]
CameraANDLiDAR/tutorials-20250802T231226Z-1-001/tutorials/librealsense/common/res/sources/D455.obj
124.0 x 29.0 x 26.0

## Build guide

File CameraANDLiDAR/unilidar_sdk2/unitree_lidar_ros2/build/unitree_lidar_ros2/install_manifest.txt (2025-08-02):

/home/jverga/CameraANDLiDAR/unilidar_sdk2/unitree_lidar_ros2/install/unitree_lidar_ros2/lib/unitree_lidar_ros2/unitree_lidar_ros2_node
/home/jverga/CameraANDLiDAR/unilidar_sdk2/unitree_lidar_ros2/install/unitree_lidar_ros2/share/unitree_lidar_ros2/view.rviz
/home/jverga/CameraANDLiDAR/unilidar_sdk2/unitree_lidar_ros2/install/unitree_lidar_ros2/share/unitree_lidar_ros2/launch.py
/home/jverga/CameraANDLiDAR/unilidar_sdk2/unitree_lidar_ros2/install/unitree_lidar_ros2/share/ament_index/resource_index/package_run_dependencies/unitree_lidar_ros2
/home/jverga/CameraANDLiDAR/unilidar_sdk2/unitree_lidar_ros2/install/unitree_lidar_ros2/share/ament_index/resource_index/parent_prefix_path/unitree_lidar_ros2
/home/jverga/CameraANDLiDAR/unilidar_sdk2/unitree_lidar_ros2/install/unitree_lidar_ros2/share/unitree_lidar_ros2/environment/ament_prefix_path.sh
/home/jverga/CameraANDLiDAR/unilidar_sdk2/unitree_lidar_ros2/install/unitree_lidar_ros2/share/unitree_lidar_ros2/environment/ament_prefix_path.dsv
/home/jverga/CameraANDLiDAR/unilidar_sdk2/unitree_lidar_ros2/install/unitree_lidar_ros2/share/unitree_lidar_ros2/environment/path.sh
/home/jverga/CameraANDLiDAR/unilidar_sdk2/unitree_lidar_ros2/install/unitree_lidar_ros2/share/unitree_lidar_ros2/environment/path.dsv
/home/jverga/CameraANDLiDAR/unilidar_sdk2/unitree_lidar_ros2/install/unitree_lidar_ros2/share/unitree_lidar_ros2/local_setup.bash
/home/jverga/CameraANDLiDAR/unilidar_sdk2/unitree_lidar_ros2/install/unitree_lidar_ros2/share/unitree_lidar_ros2/local_setup.sh
/home/jverga/CameraANDLiDAR/unilidar_sdk2/unitree_lidar_ros2/install/unitree_lidar_ros2/share/unitree_lidar_ros2/local_setup.zsh
/home/jverga/CameraANDLiDAR/unilidar_sdk2/unitree_lidar_ros2/install/unitree_lidar_ros2/share/unitree_lidar_ros2/local_setup.dsv
/home/jverga/CameraANDLiDAR/unilidar_sdk2/unitree_lidar_ros2/install/unitree_lidar_ros2/share/unitree_lidar_ros2/package.dsv
/home/jverga/CameraANDLiDAR/unilidar_sdk2/unitree_lidar_ros2/install/unitree_lidar_ros2/share/ament_index/resource_index/packages/unitree_lidar_ros2
/home/jverga/CameraANDLiDAR/unilidar_sdk2/unitree_lidar_ros2/install/unitree_lidar_ros2/share/unitree_lidar_ros2/cmake/unitree_lidar_ros2Config.cmake
/home/jverga/CameraANDLiDAR/unilidar_sdk2/unitree_lidar_ros2/install/unitree_lidar_ros2/share/unitree_lidar_ros2/cmake/unitree_lidar_ros2Config-version.cmake
/home/jverga/CameraANDLiDAR/unilidar_sdk2/unitree_lidar_ros2/install/unitree_lidar_ros2/share/unitree_lidar_ros2/package.xml

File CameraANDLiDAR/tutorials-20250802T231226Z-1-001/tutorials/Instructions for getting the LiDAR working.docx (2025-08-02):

# ✅ Unitree L2 LiDAR Setup Guide for UDP over Ethernet

This guide outlines the correct procedure to configure, compile, and test Unitree L2 LiDAR in UDP mode over Ethernet using the Unitree SDK.

## 🧾 System Setup Summary

- LiDAR IP: 192.168.1.4
- PC IP: 192.168.1.3
- Serial Port: /dev/ttyACM0
- Baudrate: 4000000
- UDP Mode WorkMode: 0
- Serial Mode WorkMode: 8

## 🛠️ Edit Required Example Files (in unitree_lidar_sdk/examples)

### 1. set_to_udp_mode.cpp ✅

No changes needed. Uses:

initializeSerial("/dev/ttyACM0", 4000000);

setLidarWorkMode(0); // UDP

### 2. set_to_serial_mode.cpp ❌

Update IPs:

std::string lidar_ip = "192.168.1.4";

std::string local_ip = "192.168.1.3";

### 3. set_ip_address.cpp ❌

- Replace UDP init with Serial:

lreader->initializeSerial("/dev/ttyACM0", 4000000);

- Update IP config:

config.lidar_ip = {192, 168, 1, 4};

config.user_ip = {192, 168, 1, 3};

### 4. example_lidar_udp.cpp ✅

Already correct:

lidar_ip = "192.168.1.4";

local_ip = "192.168.1.3";

workMode = 0;

### 5. example_lidar_serial.cpp ✅

Already correct:

initializeSerial("/dev/ttyACM0", 4000000);

workMode = 8;

## 🔧 Build Instructions

cd ~/unilidar_sdk2/unitree_lidar_sdk/build

cmake ..

make -j4

## 🔁 Configuration and Execution Sequence

### 1. Set IP Address Over Serial

../bin/set_ip_address

Expect:

Unilidar initialization succeed!

Lidar IP is reset! Please reboot lidar!

### 2. Power Cycle the LiDAR

Unplug and replug the LiDAR power. Wait 10 seconds.

### 3. Set to UDP Mode

../bin/set_to_udp_mode

### 4. Configure Network on PC

sudo ip addr add 192.168.1.3/24 dev enp0s31f6

sudo ip link set dev enp0s31f6 up

### 5. Ping the LiDAR

ping 192.168.1.4

Expect 0% packet loss.

### 6. Test UDP Communication

../bin/example_lidar_udp

Expect to see live data streaming.

## 🚀 ROS2 Node Launch Setup

### launch.py Parameter Block (must match exactly):

parameters=[

{'initialize_type': 2},

{'work_mode': 0},

{'use_system_timestamp': True},

{'range_min': 0.0},

{'range_max': 100.0},

{'cloud_scan_num': 18},

{'lidar_ip': '192.168.1.4'},

{'local_ip': '192.168.1.3'},

{'lidar_port': 6101},

{'local_port': 6201},

{'cloud_frame': 'unilidar_lidar'},

{'cloud_topic': 'unilidar/cloud'},

{'imu_frame': 'unilidar_imu'},

{'imu_topic': 'unilidar/imu'},

]

❗ Remove any serial_port or baudrate entries unless using serial mode.

### ✅ Support both Serial and UDP (Optional Dynamic Setup)

Instead of hardcoding, use:

use_udp = True

params = [

{'initialize_type': 2 if use_udp else 1},

{'work_mode': 0 if use_udp else 8},

{'use_system_timestamp': True},

{'range_min': 0.0},

{'range_max': 100.0},

{'cloud_scan_num': 18},

]

if use_udp:

params += [

{'lidar_ip': '192.168.1.4'},

{'local_ip': '192.168.1.3'},

{'lidar_port': 6101},

{'local_port': 6201},

]

else:

params += [

{'serial_port': '/dev/ttyACM0'},

{'baudrate': 4000000},

]

### 🔧 Fix ROS2 Node Name Bug

In unitree_lidar_ros2.h, update:

: Node("unitree_lidar_ros2_node", options)

This name must match name='unitree_lidar_ros2_node' in launch.py.

If it's incorrect (like unitre_lidar_sdk_node), parameters won't be passed.

### 🔧 Pass NodeOptions in Main

In unitree_lidar_ros2_node.cpp, ensure:

rclcpp::spin(std::make_shared<UnitreeLidarSDKNode>(options));

## ✅ Confirm Success

- ping 192.168.1.4 works
- ../bin/example_lidar_udp streams data
- ros2 topic echo /unilidar/cloud shows point cloud
- RViz displays /unilidar/cloud with frame unilidar_lidar

You’re done! 🎉

Let me know if you want to automate this whole setup with a shell script.

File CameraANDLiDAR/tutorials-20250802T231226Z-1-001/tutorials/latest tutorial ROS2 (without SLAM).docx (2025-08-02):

# ✅ Unitree L2 LiDAR Setup Guide for UDP over Ethernet

This guide outlines the correct procedure to configure, compile, and test Unitree L2 LiDAR in UDP mode over Ethernet using the Unitree SDK and ROS2.

## 🧾 System Setup Summary

- LiDAR IP: 192.168.1.4
- PC IP: 192.168.1.3
- Serial Port: /dev/ttyACM0
- Baudrate: 4000000
- UDP Mode WorkMode: 0
- Serial Mode WorkMode: 8

## 🧰 Initial One-Time Setup (First-Time Users)

### 1. Clone and Build the SDK and ROS2 Package

mkdir -p ~/unilidar_sdk2 && cd ~/unilidar_sdk2

git clone https://github.com/unitreerobotics/unilidar_sdk2.git

cd unilidar_sdk2/unitree_lidar_sdk

mkdir build && cd build

cmake ..

make -j4

### 2. Verify and Edit Example Files (in unitree_lidar_sdk/examples)

See section "Edit Required Example Files" below to apply the necessary edits.

### 3. Set LiDAR IP Address over Serial

cd ~/unilidar_sdk2/unitree_lidar_sdk/build

../bin/set_ip_address

Reboot the LiDAR after this step.

### 4. Set the LiDAR to UDP Mode

../bin/set_to_udp_mode

### 5. Configure PC Ethernet Interface

sudo ip addr add 192.168.1.3/24 dev enp0s31f6

sudo ip link set dev enp0s31f6 up

//sudo ip addr add 192.168.1.3/24 dev eth0

### 6. Test Ping and UDP Example

ping 192.168.1.4

../bin/example_lidar_udp

### 7. Build ROS2 Package

cd ~/unilidar_sdk2/unitree_lidar_ros2

colcon build --packages-select unitree_lidar_ros2

source install/setup.bash

## 🚀 Daily Use Instructions (After Initial Setup)

Follow these steps each time you boot the computer and want to use the LiDAR:

# Set PC Ethernet IP (if not persistent)

sudo ip addr add 192.168.1.3/24 dev enp0s31f6

sudo ip link set dev enp0s31f6 up

# Ping to confirm LiDAR connectivity

ping 192.168.1.4

# Source and run ROS2 node

cd ~/unilidar_sdk2/unitree_lidar_ros2

source install/setup.bash

ros2 launch unitree_lidar_ros2 launch.py

# In another terminal (optional):

ros2 topic echo /unilidar/cloud

## 🛠️ Edit Required Example Files (in unitree_lidar_sdk/examples)

### 1. set_to_udp_mode.cpp ✅

No changes needed:

initializeSerial("/dev/ttyACM0", 4000000);

setLidarWorkMode(0); // UDP

### 2. set_to_serial_mode.cpp ❌

Update IPs:

std::string lidar_ip = "192.168.1.4";

std::string local_ip = "192.168.1.3";

### 3. set_ip_address.cpp ❌

- Replace UDP init with Serial:

lreader->initializeSerial("/dev/ttyACM0", 4000000);

- Update IP config:

config.lidar_ip = {192, 168, 1, 4};

config.user_ip = {192, 168, 1, 3};

### 4. example_lidar_udp.cpp ✅

Already correct:

lidar_ip = "192.168.1.4";

local_ip = "192.168.1.3";

workMode = 0;

### 5. example_lidar_serial.cpp ✅

Already correct:

initializeSerial("/dev/ttyACM0", 4000000);

workMode = 8;

## 🔧 Build Instructions

cd ~/unilidar_sdk2/unitree_lidar_sdk/build

cmake ..

make -j4

## 🧩 ROS2 Launch Setup

### launch.py Parameter Block

parameters=[

{'initialize_type': 2},

{'work_mode': 0},

{'use_system_timestamp': True},

{'range_min': 0.0},

{'range_max': 100.0},

{'cloud_scan_num': 18},

{'lidar_ip': '192.168.1.4'},

{'local_ip': '192.168.1.3'},

{'lidar_port': 6101},

{'local_port': 6201},

{'cloud_frame': 'unilidar_lidar'},

{'cloud_topic': 'unilidar/cloud'},

{'imu_frame': 'unilidar_imu'},

{'imu_topic': 'unilidar/imu'},

]

❗ Remove serial_port or baudrate unless using serial mode.

### ✅ Optional Dual-Mode Setup

use_udp = True

params = [

{'initialize_type': 2 if use_udp else 1},

{'work_mode': 0 if use_udp else 8},

{'use_system_timestamp': True},

{'range_min': 0.0},

{'range_max': 100.0},

{'cloud_scan_num': 18},

]

if use_udp:

params += [

{'lidar_ip': '192.168.1.4'},

{'local_ip': '192.168.1.3'},

{'lidar_port': 6101},

{'local_port': 6201},

]

else:

params += [

{'serial_port': '/dev/ttyACM0'},

{'baudrate': 4000000},

]

### 🔧 Fix ROS2 Node Name Bug

In unitree_lidar_ros2.h, update:

: Node("unitree_lidar_ros2_node", options)

### 🔧 Pass NodeOptions in Main

In unitree_lidar_ros2_node.cpp:

rclcpp::spin(std::make_shared<UnitreeLidarSDKNode>(options));

## ✅ Confirm Success

- ping 192.168.1.4 returns packets
- ../bin/example_lidar_udp shows live stream
- ros2 topic echo /unilidar/cloud outputs point cloud data
- RViz displays /unilidar/cloud with frame unilidar_lidar

You’re done! 🎉

Let me know if you want to automate this whole setup with a shell script.

c

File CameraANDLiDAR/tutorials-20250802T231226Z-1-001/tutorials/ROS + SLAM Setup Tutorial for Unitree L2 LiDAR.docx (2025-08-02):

# ROS + SLAM Setup Tutorial for Unitree L2 LiDAR

## Overview

This guide walks you step-by-step through setting up your environment, configuring the Unitree L2 LiDAR, and running SLAM using ROS Noetic and Point-LIO. It assumes zero prior experience with ROS or LiDAR systems.

## 📦 Requirements

- Ubuntu 20.04 (preferably on a physical machine or bridged VM)
- ROS Noetic
- Unitree L2 LiDAR
- Internet connection for package installation

## 🛠️ 1. Environment Setup

### 1.1 Install ROS Noetic

sudo apt update

sudo apt install curl gnupg lsb-release

sudo sh -c 'echo "deb http://packages.ros.org/ros/ubuntu $(lsb_release -sc) main" > /etc/apt/sources.list.d/ros-latest.list'

curl -s https://raw.githubusercontent.com/ros/rosdistro/master/ros.asc | sudo apt-key add -

sudo apt update

sudo apt install ros-noetic-desktop-full

### 1.2 Initialize ROS

echo "source /opt/ros/noetic/setup.bash" >> ~/.bashrc

source ~/.bashrc

sudo apt install python3-rosdep python3-rosinstall python3-rosinstall-generator python3-wstool build-essential

sudo rosdep init

rosdep update

### 1.3 Install PCL and Eigen

sudo apt install libpcl-dev libeigen3-dev

## 🌐 2. Network Configuration

### 2.1 Configure Ethernet

Connect the Unitree L2 LiDAR to your PC using Ethernet (directly or via a switch).

### 2.2 Assign Static IP to PC

Find your Ethernet interface:

ip addr

Example output shows enp0s8. Then:

sudo ip addr add 192.168.1.3/24 dev enp0s8

### 2.3 Confirm LiDAR is Reachable

ping 192.168.1.4

Expected result: replies from 192.168.1.4

## 📁 3. Clone Required Repositories

### 3.1 Create workspace

mkdir -p ~/unilidar_sdk2 && cd ~/unilidar_sdk2

git clone https://github.com/unitreerobotics/unilidar_sdk2.git

### 3.2 Build SDK Examples

cd unilidar_sdk2/unitree_lidar_sdk

mkdir build && cd build

cmake .. && make -j4

### 3.3 Set LiDAR to UDP Mode

cd ../bin

./set_to_udp_mode

./set_ip_address

Then reboot the LiDAR.

## 🤖 4. Build and Launch ROS Driver

### 4.1 Build the ROS Package

cd ~/unilidar_sdk2/unilidar_sdk2/unitree_lidar_ros

catkin_make

source devel/setup.bash

### 4.2 Update Config

Edit src/unitree_lidar_ros/config/config.yaml:

initialize_type: 2 # UDP

lidar_ip: "192.168.1.4"

pc_ip: "192.168.1.3"

### 4.3 Run Driver

roslaunch unitree_lidar_ros run_without_rviz.launch

Leave this terminal running.

## 🧭 5. Run Point-LIO SLAM

### 5.1 Build Point-LIO

cd ~/unilidar_sdk2/unilidar_sdk2/unitree_lidar_ros

mkdir -p catkin_point_lio_unilidar/src && cd catkin_point_lio_unilidar/src

git clone https://github.com/unitreerobotics/point_lio_unilidar.git

cd ..

catkin_make

roslaunch unitree_lidar_ros run_without_rviz.launch

### 5.2 Launch Mapping

roslaunch point_lio_unilidar mapping_unilidar_l2.launch

### 5.3 View Results

rviz

- Add topic: /pointlio/laser_map
- Fixed Frame: camera_init

## 🗂️ 6. Save and View Map

After you’ve finished mapping:

pcl_viewer ~/unilidar_sdk2/.../scans.pcd

(Adjust path based on your actual workspace)

## 📌 Troubleshooting

### No PointCloud in RViz?

- Run:

rostopic hz /unilidar/cloud

- Confirm it’s publishing at ~12 Hz

### LiDAR Not Pinging?

sudo ip addr add 192.168.1.3/24 dev enp0s8

ping 192.168.1.4

### Port Busy?

sudo lsof -i :6201

## ✅ Summary Checklist

## 🙋 Need Help?

Post issues to: https://github.com/unitreerobotics/unilidar_sdk2/issues

Created by: Atombot SLAM Team Lead (2025)

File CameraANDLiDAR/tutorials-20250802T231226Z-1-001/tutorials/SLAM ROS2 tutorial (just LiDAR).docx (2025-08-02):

# Full Tutorial: Running Point-LIO SLAM on Unitree L2 LiDAR with ROS2

## Overview

This guide walks you step-by-step through setting up and running Point-LIO SLAM with the Unitree L2 LiDAR in ROS2 (Humble). It assumes zero prior ROS2 experience.

## 🧠 Prerequisites

### Hardware

- A computer running Ubuntu 22.04 LTS
- Unitree L2 LiDAR
- Ethernet port or adapter

### Software

- ROS2 Humble
- Git
- colcon
- pcl-tools

## 🔧 Step 1: Install ROS2 Humble

Follow the official guide: (https://docs.ros.org/en/humble/Installation/Ubuntu-Install-Debians.html)https://docs.ros.org/en/humble/Installation/Ubuntu-Install-Debians.html

Once done:

source /opt/ros/humble/setup.bash

Add it to your ~/.bashrc:

echo "source /opt/ros/humble/setup.bash" >> ~/.bashrc

source ~/.bashrc

## 🧱 Step 2: Install Dependencies

sudo apt update

sudo apt install -y \

ros-humble-pcl-ros \

ros-humble-pcl-conversions \

ros-humble-visualization-msgs \

libeigen3-dev \

pcl-tools \

python3-colcon-common-extensions \

build-essential \

git

## 📦 Step 3: Clone and Build the Unitree L2 ROS2 Driver

git clone https://github.com/unitreerobotics/unilidar_sdk2.git

cd unilidar_sdk2/unitree_lidar_ros2

colcon build

source install/setup.bash

Add this to ~/.bashrc:

echo "source ~/unilidar_sdk2/unitree_lidar_ros2/install/setup.bash" >> ~/.bashrc

## 🔁 Step 4: Set Up LiDAR Ethernet Communication

### Assign Static IP (computer)

sudo ip addr add 192.168.1.3/24 dev <YOUR_ETH_DEVICE>

Find your Ethernet device name via:

ip addr

It may look like enp0s31f6 or enxa0cec88d4989.

### Set LiDAR IP (only once or when resetting)

cd ~/unilidar_sdk2/unitree_lidar_sdk/build

../bin/set_ip_address # sets IP to 192.168.1.4

../bin/set_to_udp_mode

Now reboot the LiDAR:

- Unplug power
- Wait 15 sec
- Plug back in
- Wait 20+ sec

### Test ping:

ping 192.168.1.4

If it replies, you're connected!

## 🧠 Step 5: Clone and Build Point-LIO (ROS2)

cd ~/unilidar_sdk2/unitree_lidar_ros2

mkdir catkin_point_lio_unilidar && cd catkin_point_lio_unilidar

mkdir src && cd src

# Clone Point-LIO with Unitree support

git clone https://github.com/dfloreaa/point_lio_ros2.git

cd ..

colcon build --symlink-install

source install/setup.bash

Add to ~/.bashrc:

echo "source ~/unilidar_sdk2/unitree_lidar_ros2/catkin_point_lio_unilidar/install/setup.bash" >> ~/.bashrc

## 🧾 Step 6: Edit the YAML Config File

Edit unilidar_l2.yaml inside point_lio/config/.

Ensure these key parameters are set:

lid_topic: "/unilidar/cloud"

imu_topic: "/unilidar/imu"

mapping:

imu_en: true

extrinsic_est_en: false

extrinsic_T: [0.007698, 0.014655, -0.00667]

extrinsic_R: [1.0, 0.0, 0.0,

0.0, 1.0, 0.0,

0.0, 0.0, 1.0]

gravity: [0.0, 0.0, -9.810]

## 🚀 Step 7: Enable Map Saving (Optional but Recommended)

In mapping_unilidar_l2.launch.py, locate laser_mapping_params and append:

'pcd_save_en': True,

'pcd_save_interval': -1

## ▶️ Step 8: Run SLAM

### Terminal 1: Start Unitree Driver

cd ~/unilidar_sdk2/unitree_lidar_ros2

source install/setup.bash

ros2 launch unitree_lidar_ros2 launch.py

### Terminal 2: Start Point-LIO

cd ~/unilidar_sdk2/unitree_lidar_ros2/catkin_point_lio_unilidar

source install/setup.bash

ros2 launch point_lio mapping_unilidar_l2.launch.py

Walk around slowly. After 5–10 seconds, you'll see points accumulate in RViz.

## 💾 Step 9: View Saved Map

Once done, stop with Ctrl+C. The map will be saved to:

~/unilidar_sdk2/unitree_lidar_ros2/catkin_point_lio_unilidar/PCD/scans.pcd

View it with:

pcl_viewer ~/unilidar_sdk2/unitree_lidar_ros2/catkin_point_lio_unilidar/PCD/scans.pcd

Use keys 1–5 in the viewer to change visualization styles.

## 🧼 Optional Cleanup

To prevent IP conflicts, remove duplicate static assignments:

sudo ip addr del 192.168.1.3/24 dev <any_wrong_interface>

## ✅ Troubleshooting

Problem | Solution
Cannot ping LiDAR | Ensure Ethernet IP is set to 192.168.1.3 and LiDAR is rebooted
RViz shows blank | Wait longer, confirm topics /cloud_registered or /Laser_map are live
No scans saved | Ensure 'pcd_save_en': True is in your launch file
pcl_viewer not found | Install: sudo apt install pcl-tools

## 🎉 Done!

You now have a working Point-LIO SLAM system with the Unitree L2. You can use the .pcd file for 3D reconstruction, analysis, or navigation experiments.

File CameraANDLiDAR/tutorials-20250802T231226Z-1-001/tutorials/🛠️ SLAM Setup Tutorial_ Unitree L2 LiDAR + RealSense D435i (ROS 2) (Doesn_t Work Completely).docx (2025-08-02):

# 🛠️ SLAM Setup Tutorial: Unitree L2 LiDAR + RealSense D435i (ROS 2)

This guide documents every step to replicate a working SLAM setup that combines:

- 3D LiDAR data from Unitree L2
- IMU + RGBD data from Intel RealSense D435i
- Odometry fusion via a custom ROS 2 node

Designed for beginners and advanced users alike.

## 🔧 System Requirements

- Ubuntu 20.04
- ROS 2 Humble installed
- Internet access for cloning packages
- USB 3.0 port for RealSense
- Ethernet for Unitree L2

## 📁 Workspace Setup

bash

CopyEdit

mkdir -p ~/combined_ros2_ws/src

cd ~/combined_ros2_ws/src

## 🔌 Step 1: LiDAR Setup

### 1. Clone the Unitree L2 ROS2 driver

bash

CopyEdit

git clone https://github.com/unitreerobotics/unilidar_sdk2.git

### 2. Configure LiDAR to UDP mode

bash

CopyEdit

cd /unilidar_sdk2/unitree_lidar_sdk/examples

./set_to_udp_mode

./set_ip_address

Make sure your LiDAR IP is set to 192.168.1.4 and your PC to 192.168.1.3.

## 📷 Step 2: RealSense Camera Setup

bash

CopyEdit

cd ~/combined_ros2_ws/src

git clone -b ros2-master https://github.com/IntelRealSense/realsense-ros.git

You will primarily use:

- /camera/camera/imu
- /camera/camera/depth/color/points

To launch:

bash

CopyEdit

source /opt/ros/humble/setup.bash

ros2 launch realsense2_camera rs_launch.py pointcloud.enable:=true enable_gyro:=true enable_accel:=true unite_imu_method:=2

## 🧠 Step 3: Point-LIO SLAM for LiDAR

bash

CopyEdit

cd ~/combined_ros2_ws/src

git clone https://github.com/dfloreaa/point_lio_ros2.git

Then:

bash

CopyEdit

cd ~/combined_ros2_ws

rosdep install --from-paths src --ignore-src -r -y

colcon build --symlink-install

source install/setup.bash

To launch Point-LIO SLAM:

bash

CopyEdit

ros2 launch point_lio mapping_unilidar_l2.launch.py

## 📦 Step 4: Odometry Fusion Node

### 1. Create Package

bash

CopyEdit

cd ~/combined_ros2_ws/src

ros2 pkg create --build-type ament_python odometry_fusion

### 2. Add Node File

Create: ~/combined_ros2_ws/src/odometry_fusion/odometry_fusion/odometry_fusion_node.py

python

CopyEdit

import rclpy

from rclpy.node import Node

from nav_msgs.msg import Odometry

from sensor_msgs.msg import Imu

class OdometryFusionNode(Node):

def __init__(self):

super().__init__('odometry_fusion_node')

self.sub_odom = self.create_subscription(Odometry, '/odom_lidar', self.odom_callback, 10)

self.sub_imu = self.create_subscription(Imu, '/imu_camera', self.imu_callback, 10)

self.pub_fused = self.create_publisher(Odometry, '/fused_odometry', 10)

self.latest_odom = None

self.latest_imu = None

def odom_callback(self, msg):

self.latest_odom = msg

self.publish_fused()

def imu_callback(self, msg):

self.latest_imu = msg

self.publish_fused()

def publish_fused(self):

if self.latest_odom and self.latest_imu:

fused = self.latest_odom

fused.header.stamp = self.latest_imu.header.stamp

fused.twist.twist.angular = self.latest_imu.angular_velocity

fused.twist.twist.linear = self.latest_odom.twist.twist.linear

self.pub_fused.publish(fused)

def main():

rclpy.init()

node = OdometryFusionNode()

rclpy.spin(node)

node.destroy_node()

rclpy.shutdown()

if __name__ == '__main__':

main()

### 3. Update setup.py

python

CopyEdit

entry_points={

'console_scripts': [

'odometry_fusion_node = odometry_fusion.odometry_fusion_node:main'

],

}

### 4. Add Launch File

Create: ~/combined_ros2_ws/src/odometry_fusion/launch/odometry_fusion_launch.py

python

CopyEdit

from launch import LaunchDescription

from launch_ros.actions import Node

def generate_launch_description():

return LaunchDescription([

Node(

package='odometry_fusion',

executable='odometry_fusion_node',

name='odometry_fusion_node',

output='screen',

remappings=[

('/odom_lidar', '/Odometry'),

('/imu_camera', '/camera/camera/imu'),

('/fused_odom', '/fused_odometry')

]

)

])

### 5. Build the Workspace

bash

CopyEdit

cd ~/combined_ros2_ws

colcon build --symlink-install

source install/setup.bash

## 🧪 Step 5: Run All Nodes in Separate Terminals

- Terminal 1: LiDAR ROS2 driver

bash

CopyEdit

ros2 launch unitree_lidar_ros2 launch.py

- Terminal 2: RealSense camera

bash

CopyEdit

ros2 launch realsense2_camera rs_launch.py pointcloud.enable:=true enable_gyro:=true enable_accel:=true unite_imu_method:=2

- Terminal 3: Point-LIO SLAM

bash

CopyEdit

ros2 launch point_lio mapping_unilidar_l2.launch.py

- Terminal 4: Odometry fusion

bash

CopyEdit

ros2 launch odometry_fusion odometry_fusion_launch.py

- Terminal 5: RViz2 to visualize /fused_odometry and /unilidar/cloud

bash

CopyEdit

rviz2

Set:

- Fixed Frame: camera_link
- Add:
  - PointCloud2 (topic: /unilidar/cloud)
  - Odometry (topic: /fused_odometry)

## ✅ Verification

Run:

bash

CopyEdit

ros2 topic echo /fused_odometry

ros2 run tf2_tools view_frames

You should see the fused odometry stream and a connected TF tree with camera_link, unilidar_lidar, and aft_mapped.

## 📄 Downloadable Version

A downloadable README.md file is provided below:

👉 Download README.md

Let me know if you want this turned into a PDF, hosted on GitHub, or converted into a step-by-step bash script.

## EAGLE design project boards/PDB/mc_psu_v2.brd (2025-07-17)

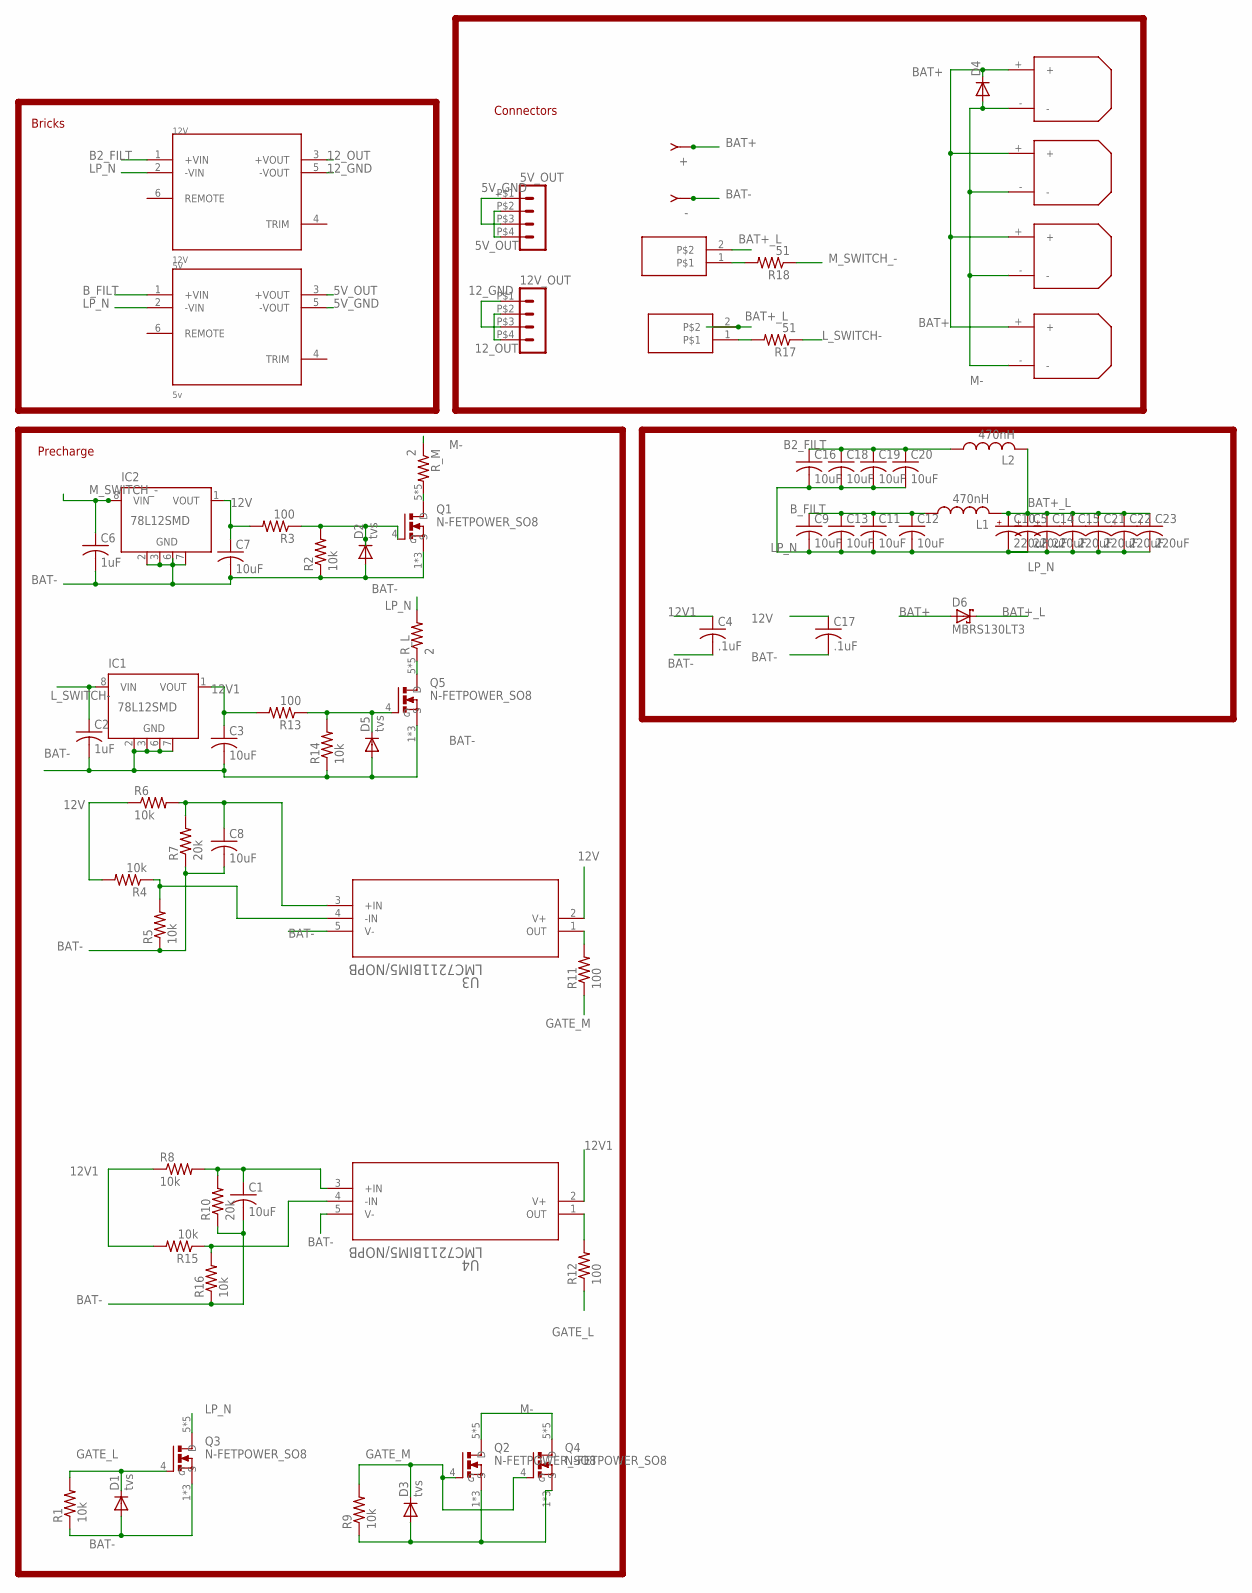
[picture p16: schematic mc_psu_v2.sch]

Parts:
5V: 5v; CONV_PDQ30-Q24-S5-D
5V_OUT, 12V_OUT: HEADER_POS4_43045-0401; 43045-0400
12V: 12V; CONV_PDQ30-Q24-S5-D
+: QFIT; FASTON
-: QFIT; FASTON
C1, C3, C7, C8: 10uF; C0603K
C2, C6: 1uF; C0603K
C4, C17: .1uF; C0603K
C5, C10, C14, C15, C21, C22, C23: 220uF; E3,5-8
C9, C11, C12, C13, C16, C18, C19, C20: 10uF; C1206K
D1, D2, D3, D5: tvs; DO214AC
D4: DIODE-SMB; SMB
D6: MBRS130LT3; SMB
IC1, IC2: 78L12SMD; SO08
L1, L2: 470nH; L3225P
Q1, Q2, Q3, Q4, Q5: N-FETPOWER_SO8; TRANS_TPH5900CNH,L1Q
R1, R2, R4, R5, R6, R8, R9, R14, R15, R16: 10k; R0402
R3, R11, R12, R13: 100; R0402
R7, R10: 20k; R0402
R17, R18: 51; R0603
R_L: 2; D2PAK
R_M: 2; D2PAK
U3, U4: LMC7211BIM5/NOPB; MF05A
U$3, U$8, U$9, U$10: XT30FEMALW; XT30_H_F
U$13, U$14: 2-PINM80_H; M80-840242

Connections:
5V_GND: 5V.5 (-VOUT), 5V_OUT.P$1 (1), 5V_OUT.P$3 (3)
5V_OUT: 5V.3 (+VOUT), 5V_OUT.P$2 (2), 5V_OUT.P$4 (4)
12V: C7.1, C17.1, IC2.1 (VOUT), R3.2, R4.2, R6.1, U3.2 (V+)
12V1: C3.1, C4.1, IC1.1 (VOUT), R8.1, R13.2, R15.2, U4.2 (V+)
12_GND: 12V.5 (-VOUT), 12V_OUT.P$1 (1), 12V_OUT.P$3 (3)
12_OUT: 12V.3 (+VOUT), 12V_OUT.P$2 (2), 12V_OUT.P$4 (4)
B2_FILT: 12V.1 (+VIN), C16.1, C18.1, C19.1, C20.1, L2.1
BAT+: +.1, +.2, D4.C, D6.A, U$3.+, U$8.+, U$9.+, U$10.+
BAT+_L: C5.+, C10.+, C14.+, C15.+, C21.+, C22.+, C23.+, D6.C, L1.2, L2.2, U$13.2, U$14.2
BAT-: -.1, -.2, C1.2, C2.2, C3.2, C4.2, C6.2, C7.2, C8.2, C17.2, D1.A, D2.A, D3.A, D5.A, IC1.2 (GND), IC1.3 (GND), IC1.6 (GND), IC1.7 (GND), IC2.2 (GND), IC2.3 (GND), IC2.6 (GND), IC2.7 (GND), Q1.1 (S), Q1.2 (S), Q1.3 (S), Q2.1 (S), Q2.2 (S), Q2.3 (S), Q3.1 (S), Q3.2 (S), Q3.3 (S), Q4.1 (S), Q4.2 (S), Q4.3 (S), Q5.1 (S), Q5.2 (S), Q5.3 (S), R1.1, R2.1, R5.1, R7.1, R9.1, R10.1, R14.1, R16.1, U3.5 (V-), U4.5 (V-)
B_FILT: 5V.1 (+VIN), C9.1, C11.1, C12.1, C13.1, L1.1
GATE_L: D1.C, Q3.4 (G), R1.2, R12.1
GATE_M: D3.C, Q2.4 (G), Q4.4 (G), R9.2, R11.1
LP_N: 5V.2 (-VIN), 12V.2 (-VIN), C5.-, C9.2, C10.-, C11.2, C12.2, C13.2, C14.-, C15.-, C16.2, C18.2, C19.2, C20.2, C21.-, C22.-, C23.-, Q3.5 (D), Q3.6 (D), Q3.7 (D), Q3.8 (D), Q3.EP (D), R_L.3 (2)
L_SWITCH-: C2.1, IC1.8 (VIN), R17.1
M-: D4.A, Q2.5 (D), Q2.6 (D), Q2.7 (D), Q2.8 (D), Q2.EP (D), Q4.5 (D), Q4.6 (D), Q4.7 (D), Q4.8 (D), Q4.EP (D), R_M.1, U$3.-, U$8.-, U$9.-, U$10.-
M_SWITCH_-: C6.1, IC2.8 (VIN), R18.1
unnamed: Q1.5 (D), Q1.6 (D), Q1.7 (D), Q1.8 (D), Q1.EP (D), R_M.3 (2)
unnamed: D5.C, Q5.4 (G), R13.1, R14.2
unnamed: D2.C, Q1.4 (G), R2.2, R3.1
unnamed: R12.2, U4.1 (OUT)
unnamed: R18.2, U$13.1
unnamed: C1.1, R8.2, R10.2, U4.3 (+IN)
unnamed: C8.1, R6.2, R7.2, U3.3 (+IN)
unnamed: R17.2, U$14.1
unnamed: R11.2, U3.1 (OUT)
unnamed: R4.1, R5.2, U3.4 (-IN)
unnamed: Q5.5 (D), Q5.6 (D), Q5.7 (D), Q5.8 (D), Q5.EP (D), R_L.1
unnamed: R15.1, R16.2, U4.4 (-IN)

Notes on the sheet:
Bricks
Precharge
Connectors

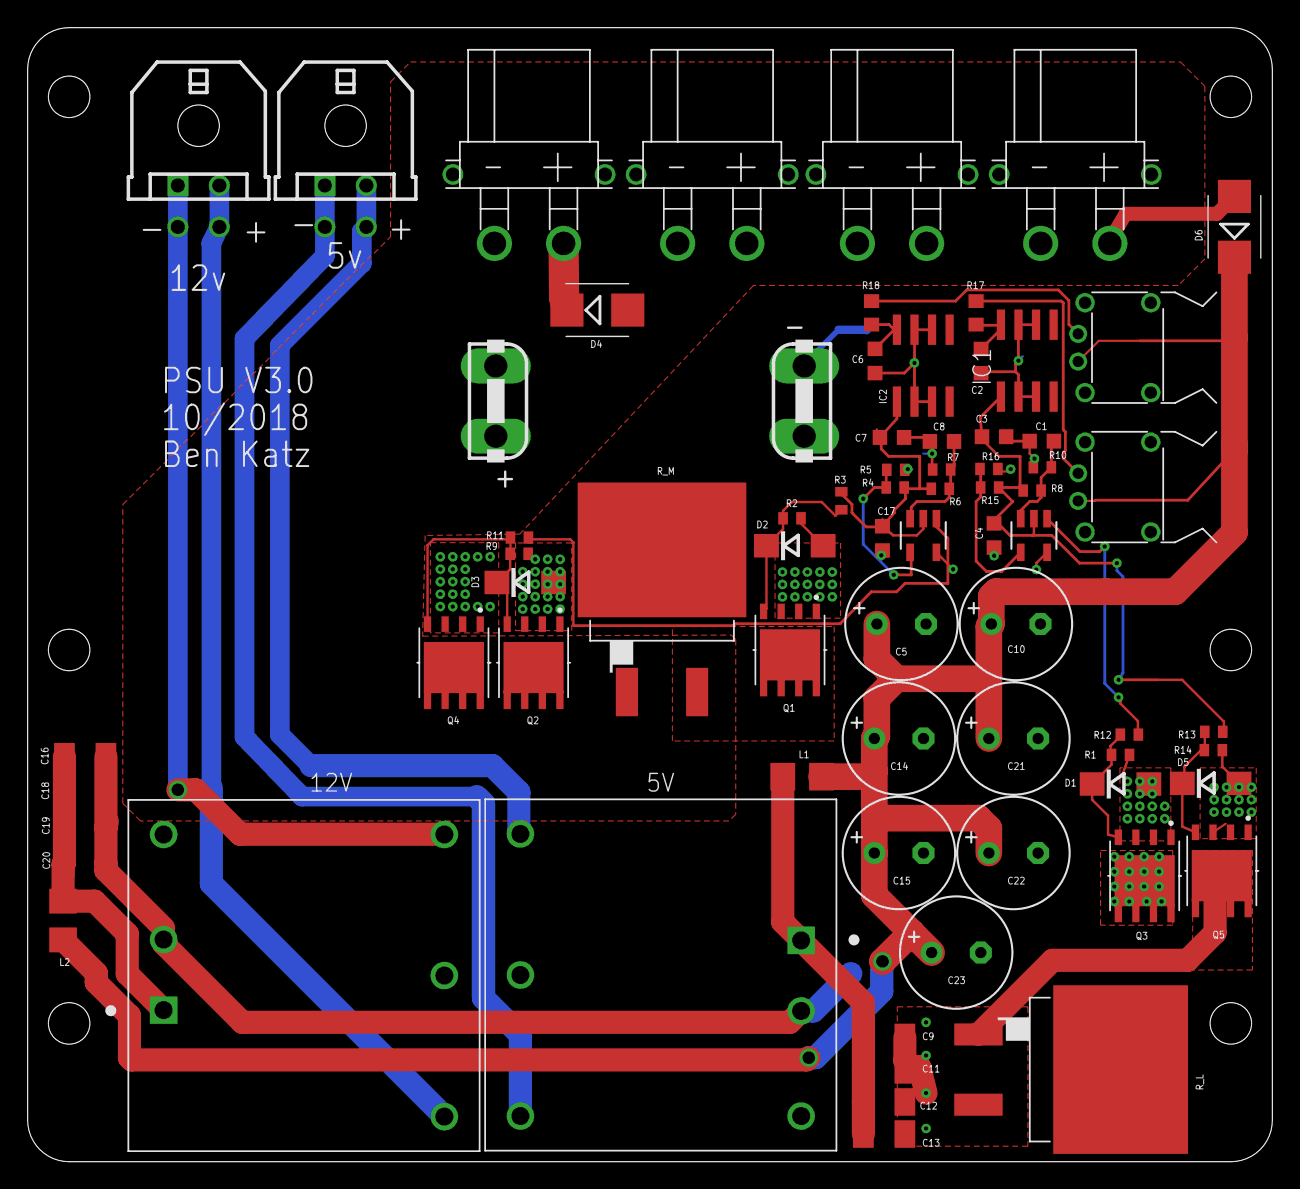
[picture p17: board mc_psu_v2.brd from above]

Board: 2 copper layers, 90.0 x 82.0 mm, 72 parts (0 on the bottom side), 29 nets.

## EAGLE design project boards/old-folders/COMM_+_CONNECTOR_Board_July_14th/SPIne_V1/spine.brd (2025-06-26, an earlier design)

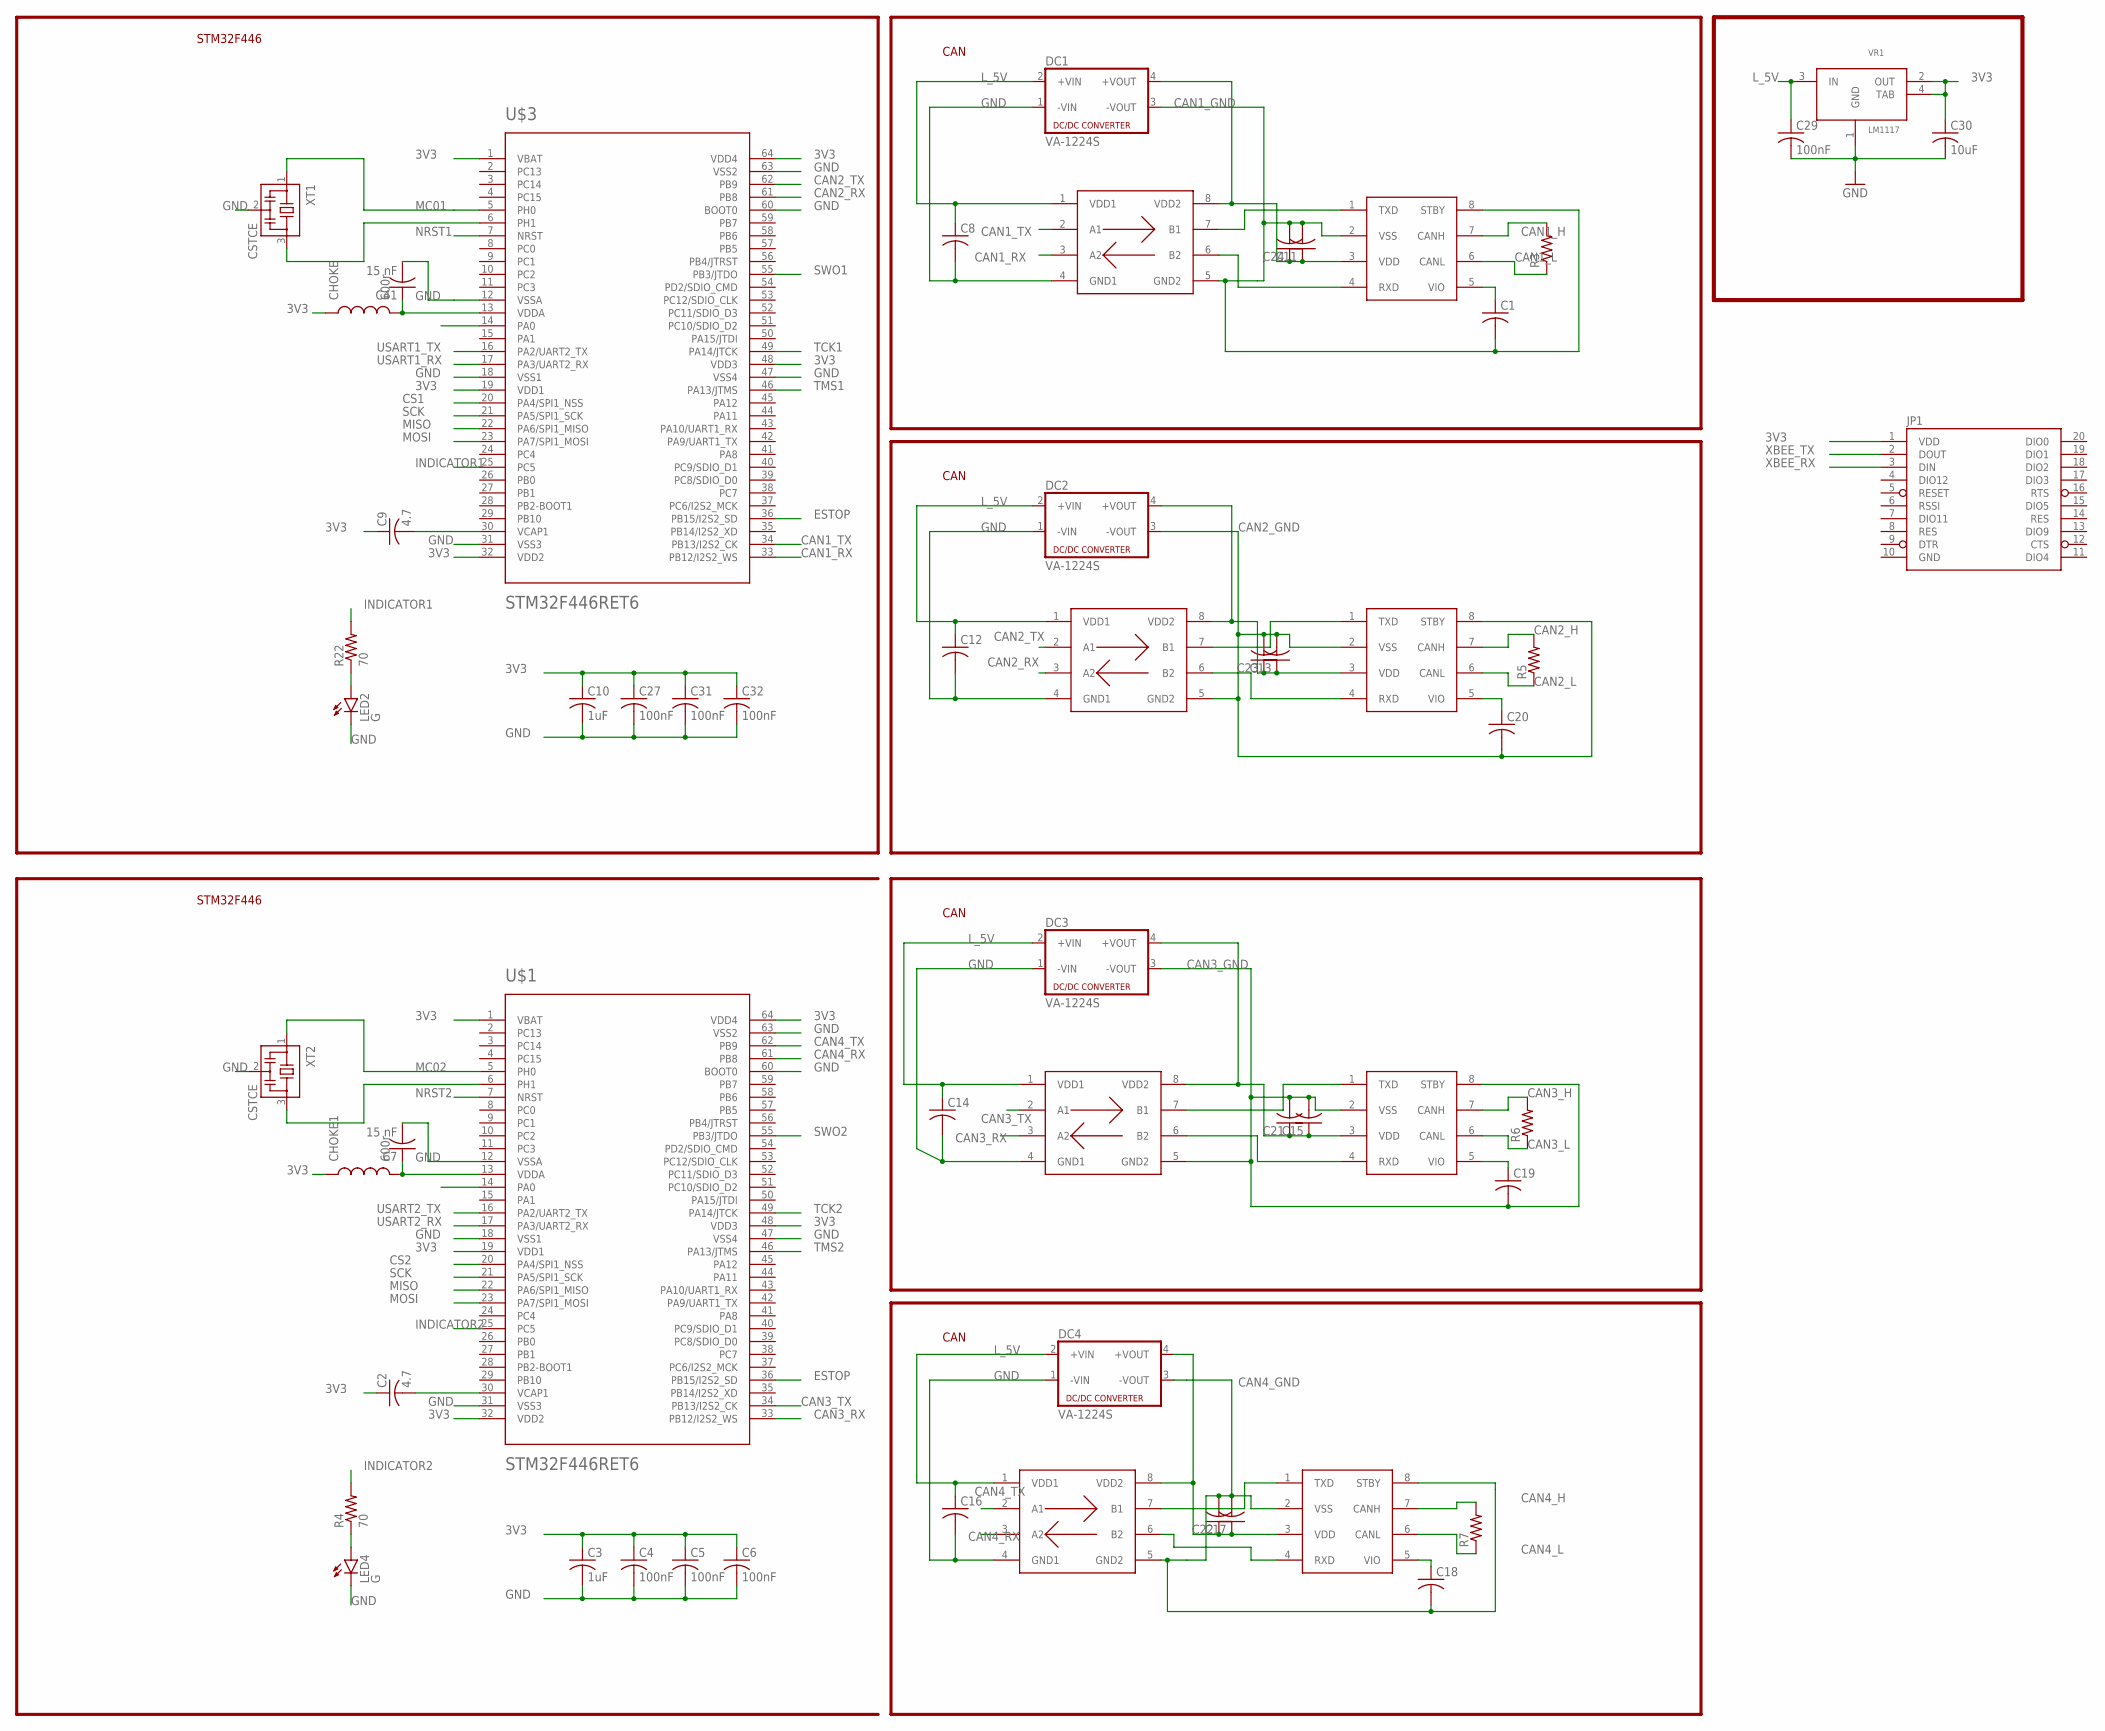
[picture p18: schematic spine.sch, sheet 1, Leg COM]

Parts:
C1, C8, C11, C12, C13, C14, C15, C16, C17, C18, C19, C20, C21, C22, C23, C24: C-USC0603K; C0603K
C2, C9: 4.7; C0603
C3, C10: 1uF; C0603
C4, C5, C6, C27, C29, C31, C32: 100nF; C0603
C7, C41: 15 nF; C0603
C30: 10uF; C0805K
CHOKE, CHOKE1: 600r; 0603
DC1, DC2, DC3, DC4: VA-1224S; 4SIL
JP1: XBEE-1B1; XBEE-1
LED2, LED4: G; LED-0603
R3, R5, R6, R7: R-US_R0603; R0603
R4, R22: 70; R0603
U$1, U$3: STM32F446RET6; TQFP64
U$4, U$5, U$6, U$7: MCP2561; SO08
U$8, U$9, U$10, U$11: SI8410; SO08
VR1: LM1117; SOT-223
XT1, XT2: CSTCE

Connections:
3V3: C2.1, C3.1, C4.1, C5.1, C6.1, C9.1, C10.1, C27.1, C30.1, C31.1, C32.1, CHOKE.1, CHOKE1.1, JP1.1 (VDD), U$1.1 (VBAT), U$1.19 (VDD1), U$1.32 (VDD2), U$1.48 (VDD3), U$1.64 (VDD4), U$3.1 (VBAT), U$3.19 (VDD1), U$3.32 (VDD2), U$3.48 (VDD3), U$3.64 (VDD4), VR1.2 (OUT), VR1.4 (TAB); also elsewhere on the board
CAN1_GND: C1.2, C11.2, C24.2, DC1.3 (-VOUT), U$4.2 (VSS), U$4.8 (STBY), U$8.5 (GND2); also elsewhere on the board
CAN1_H: R3.2, U$4.7 (CANH); also elsewhere on the board
CAN1_L: R3.1, U$4.6 (CANL); also elsewhere on the board
CAN1_RX: U$3.33 (PB12/I2S2_WS), U$8.3 (A2)
CAN1_TX: U$3.34 (PB13/I2S2_CK), U$8.2 (A1)
CAN2_GND: C13.2, C20.2, C23.2, DC2.3 (-VOUT), U$5.2 (VSS), U$5.8 (STBY), U$10.5 (GND2); also elsewhere on the board
CAN2_H: R5.2, U$5.7 (CANH); also elsewhere on the board
CAN2_L: R5.1, U$5.6 (CANL); also elsewhere on the board
CAN2_RX: U$3.61 (PB8), U$10.3 (A2)
CAN2_TX: U$3.62 (PB9), U$10.2 (A1)
CAN3_GND: C15.2, C19.2, C21.2, DC3.3 (-VOUT), U$6.2 (VSS), U$6.8 (STBY), U$9.5 (GND2); also elsewhere on the board
CAN3_H: R6.2, U$6.7 (CANH); also elsewhere on the board
CAN3_L: R6.1, U$6.6 (CANL); also elsewhere on the board
CAN3_RX: U$1.33 (PB12/I2S2_WS), U$9.3 (A2)
CAN3_TX: U$1.34 (PB13/I2S2_CK), U$9.2 (A1)
CAN4_GND: C17.2, C18.2, C22.2, DC4.3 (-VOUT), U$7.2 (VSS), U$7.8 (STBY), U$11.5 (GND2); also elsewhere on the board
CAN4_H: R7.2, U$7.7 (CANH); also elsewhere on the board
CAN4_L: R7.1, U$7.6 (CANL); also elsewhere on the board
CAN4_RX: U$1.61 (PB8), U$11.3 (A2)
CAN4_TX: U$1.62 (PB9), U$11.2 (A1)
CS1: U$3.20 (PA4/SPI1_NSS); also elsewhere on the board
CS2: U$1.20 (PA4/SPI1_NSS); also elsewhere on the board
ESTOP: U$1.36 (PB15/I2S2_SD), U$3.36 (PB15/I2S2_SD); also elsewhere on the board
GND: C3.2, C4.2, C5.2, C6.2, C7.2, C8.2, C10.2, C12.2, C14.2, C16.2, C27.2, C29.2, C30.2, C31.2, C32.2, C41.2, DC1.1 (-VIN), DC2.1 (-VIN), DC3.1 (-VIN), DC4.1 (-VIN), JP1.10 (GND), LED2.C, LED4.C, U$1.12 (VSSA), U$1.18 (VSS1), U$1.31 (VSS3), U$1.47 (VSS4), U$1.60 (BOOT0), U$1.63 (VSS2), U$3.12 (VSSA), U$3.18 (VSS1), U$3.31 (VSS3), U$3.47 (VSS4), U$3.60 (BOOT0), U$3.63 (VSS2), U$8.4 (GND1), U$9.4 (GND1), U$10.4 (GND1), U$11.4 (GND1), VR1.1 (GND), XT1.2, XT2.2; also elsewhere on the board
INDICATOR1: R22.2, U$3.25 (PC5)
INDICATOR2: R4.2, U$1.25 (PC5)
L_5V: C8.1, C12.1, C14.1, C16.1, C29.1, DC1.2 (+VIN), DC2.2 (+VIN), DC3.2 (+VIN), DC4.2 (+VIN), U$8.1 (VDD1), U$9.1 (VDD1), U$10.1 (VDD1), U$11.1 (VDD1), VR1.3 (IN); also elsewhere on the board
MC01: U$3.5 (PH0), XT1.1
MC02: U$1.5 (PH0), XT2.1
MISO: U$1.22 (PA6/SPI1_MISO), U$3.22 (PA6/SPI1_MISO); also elsewhere on the board
MOSI: U$1.23 (PA7/SPI1_MOSI), U$3.23 (PA7/SPI1_MOSI); also elsewhere on the board
unnamed: C41.1, CHOKE.2, U$3.13 (VDDA)
unnamed: C9.2, U$3.30 (VCAP1)
unnamed: C7.1, CHOKE1.2, U$1.13 (VDDA)
unnamed: C2.2, U$1.30 (VCAP1)
unnamed: C1.1, U$4.5 (VIO)
unnamed: LED4.A, R4.1
unnamed: U$1.6 (PH1), XT2.3
unnamed: C17.1, C22.1, DC4.4 (+VOUT), U$7.3 (VDD), U$11.8 (VDD2)
unnamed: C20.1, U$5.5 (VIO)
unnamed: C15.1, C21.1, DC3.4 (+VOUT), U$6.3 (VDD), U$9.8 (VDD2)
unnamed: C11.1, C24.1, DC1.4 (+VOUT), U$4.3 (VDD), U$8.8 (VDD2)
unnamed: U$4.1 (TXD), U$8.7 (B1)
unnamed: U$7.1 (TXD), U$11.7 (B1)
unnamed: U$4.4 (RXD), U$8.6 (B2)
unnamed: U$7.4 (RXD), U$11.6 (B2)
unnamed: C18.1, U$7.5 (VIO)
unnamed: C13.1, C23.1, DC2.4 (+VOUT), U$5.3 (VDD), U$10.8 (VDD2)
unnamed: U$5.1 (TXD), U$10.7 (B1)
unnamed: U$5.4 (RXD), U$10.6 (B2)
unnamed: C19.1, U$6.5 (VIO)
unnamed: U$6.1 (TXD), U$9.7 (B1)
unnamed: U$6.4 (RXD), U$9.6 (B2)
unnamed: LED2.A, R22.1
unnamed: U$3.6 (PH1), XT1.3
NRST1: U$3.7 (NRST); also elsewhere on the board
NRST2: U$1.7 (NRST); also elsewhere on the board
SCK: U$1.21 (PA5/SPI1_SCK), U$3.21 (PA5/SPI1_SCK); also elsewhere on the board
SWO1: U$3.55 (PB3/JTDO); also elsewhere on the board
SWO2: U$1.55 (PB3/JTDO); also elsewhere on the board
TCK1: U$3.49 (PA14/JTCK); also elsewhere on the board
TCK2: U$1.49 (PA14/JTCK); also elsewhere on the board
TMS1: U$3.46 (PA13/JTMS); also elsewhere on the board
TMS2: U$1.46 (PA13/JTMS); also elsewhere on the board
USART1_RX: U$3.17 (PA3/UART2_RX); also elsewhere on the board
USART1_TX: U$3.16 (PA2/UART2_TX); also elsewhere on the board
USART2_RX: U$1.17 (PA3/UART2_RX); also elsewhere on the board
USART2_TX: U$1.16 (PA2/UART2_TX); also elsewhere on the board
XBEE_RX: JP1.3 (DIN); also elsewhere on the board
XBEE_TX: JP1.2 (DOUT); also elsewhere on the board

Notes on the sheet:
STM32F446
CAN

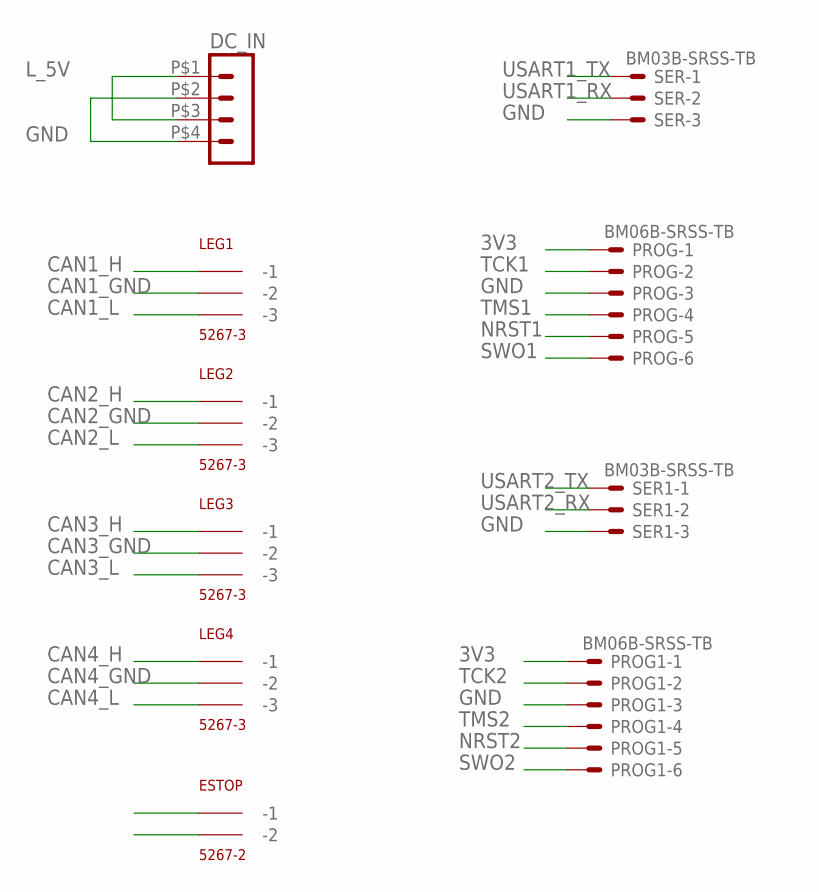
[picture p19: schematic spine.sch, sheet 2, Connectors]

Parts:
DC_IN: HEADER_POS4_43045-0401; 43045-0400
ESTOP: 5267-2
LEG1, LEG2, LEG3, LEG4: 5267-3
PROG, PROG1: BM06B-SRSS-TB
SER, SER1: BM03B-SRSS-TB

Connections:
3V3: PROG.1, PROG1.1; also elsewhere on the board
CAN1_GND: LEG1.P$2 (-2); also elsewhere on the board
CAN1_H: LEG1.P$1 (-1); also elsewhere on the board
CAN1_L: LEG1.P$3 (-3); also elsewhere on the board
CAN2_GND: LEG2.P$2 (-2); also elsewhere on the board
CAN2_H: LEG2.P$1 (-1); also elsewhere on the board
CAN2_L: LEG2.P$3 (-3); also elsewhere on the board
CAN3_GND: LEG3.P$2 (-2); also elsewhere on the board
CAN3_H: LEG3.P$1 (-1); also elsewhere on the board
CAN3_L: LEG3.P$3 (-3); also elsewhere on the board
CAN4_GND: LEG4.P$2 (-2); also elsewhere on the board
CAN4_H: LEG4.P$1 (-1); also elsewhere on the board
CAN4_L: LEG4.P$3 (-3); also elsewhere on the board
ESTOP: ESTOP.P$2 (-2); also elsewhere on the board
GND: DC_IN.P$2 (2), DC_IN.P$4 (4), ESTOP.P$1 (-1), PROG.3, PROG1.3, SER.3, SER1.3; also elsewhere on the board
L_5V: DC_IN.P$1 (1), DC_IN.P$3 (3); also elsewhere on the board
NRST1: PROG.5; also elsewhere on the board
NRST2: PROG1.5; also elsewhere on the board
SWO1: PROG.6; also elsewhere on the board
SWO2: PROG1.6; also elsewhere on the board
TCK1: PROG.2; also elsewhere on the board
TCK2: PROG1.2; also elsewhere on the board
TMS1: PROG.4; also elsewhere on the board
TMS2: PROG1.4; also elsewhere on the board
USART1_RX: SER.2; also elsewhere on the board
USART1_TX: SER.1; also elsewhere on the board
USART2_RX: SER1.2; also elsewhere on the board
USART2_TX: SER1.1; also elsewhere on the board

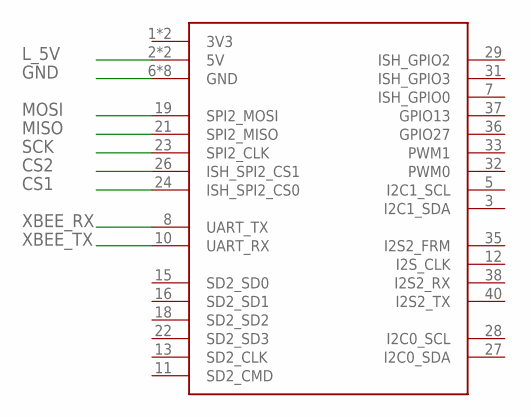
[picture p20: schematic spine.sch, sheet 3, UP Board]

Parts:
U$2: UP_BOARD

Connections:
CS1: U$2.24 (ISH_SPI2_CS0); also elsewhere on the board
CS2: U$2.26 (ISH_SPI2_CS1); also elsewhere on the board
GND: U$2.6 (GND), U$2.9 (GND), U$2.14 (GND), U$2.20 (GND), U$2.25 (GND), U$2.30 (GND), U$2.34 (GND), U$2.39 (GND); also elsewhere on the board
L_5V: U$2.2 (5V), U$2.4 (5V); also elsewhere on the board
MISO: U$2.21 (SPI2_MISO); also elsewhere on the board
MOSI: U$2.19 (SPI2_MOSI); also elsewhere on the board
SCK: U$2.23 (SPI2_CLK); also elsewhere on the board
XBEE_RX: U$2.8 (UART_TX); also elsewhere on the board
XBEE_TX: U$2.10 (UART_RX); also elsewhere on the board

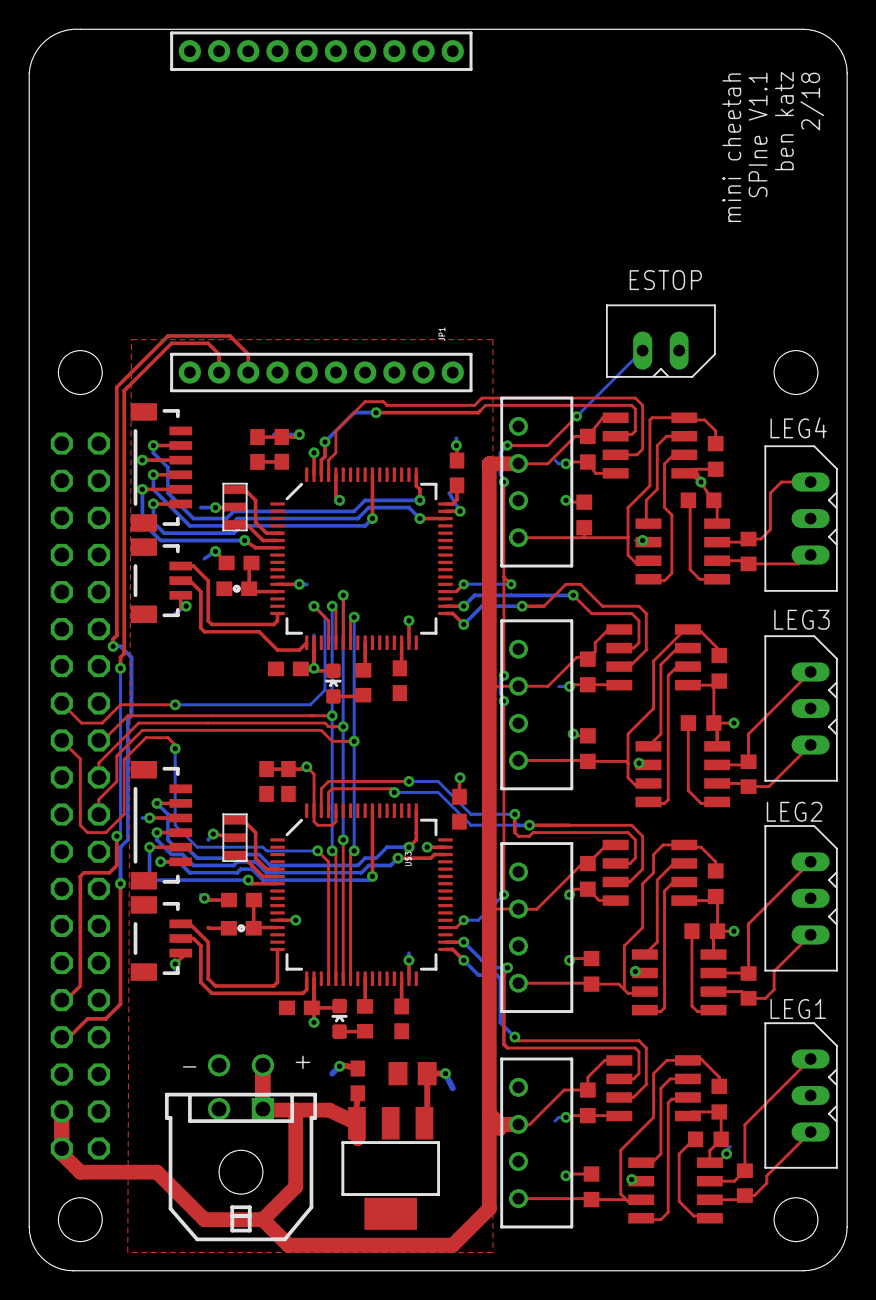
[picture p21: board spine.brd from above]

Board: 2 copper layers, 56.0 x 85.0 mm, 69 parts (0 on the bottom side), 71 nets.

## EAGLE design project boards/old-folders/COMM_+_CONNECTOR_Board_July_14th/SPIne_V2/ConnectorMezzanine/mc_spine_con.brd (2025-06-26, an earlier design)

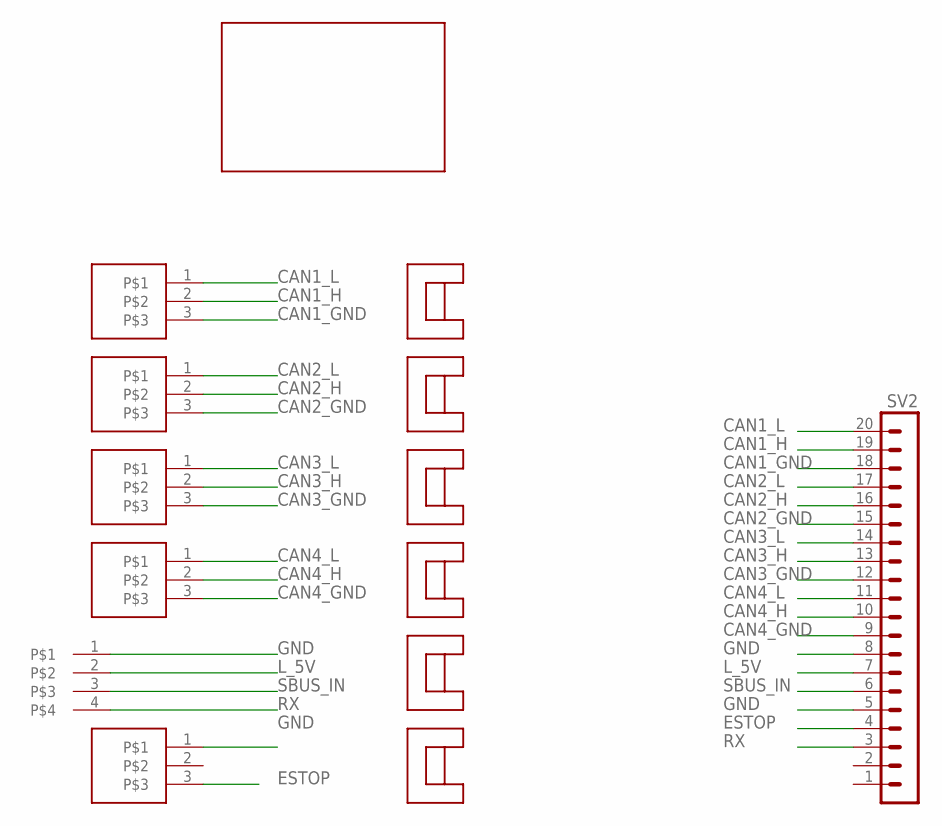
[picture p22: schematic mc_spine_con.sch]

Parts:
SV2: MA20-1L
U$1, U$3, U$4, U$6, U$12: 3-PIN; M80-8430342
U$2: UP_BOARD_NOPINS
U$5: 4-PIN; M80-8430442
U$7, U$8, U$9, U$10, U$11, U$13: SMD_CABLE_CLIPSS8111-46R; S8111-46R

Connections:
CAN1_GND: SV2.18, U$12.3
CAN1_H: SV2.19, U$12.2
CAN1_L: SV2.20, U$12.1
CAN2_GND: SV2.15, U$1.3
CAN2_H: SV2.16, U$1.2
CAN2_L: SV2.17, U$1.1
CAN3_GND: SV2.12, U$3.3
CAN3_H: SV2.13, U$3.2
CAN3_L: SV2.14, U$3.1
CAN4_GND: SV2.9, U$4.3
CAN4_H: SV2.10, U$4.2
CAN4_L: SV2.11, U$4.1
ESTOP: SV2.4, U$6.3
GND: SV2.5, SV2.8, U$5.1, U$6.1
L_5V: SV2.7, U$5.2
RX: SV2.3, U$5.4
SBUS_IN: SV2.6, U$5.3

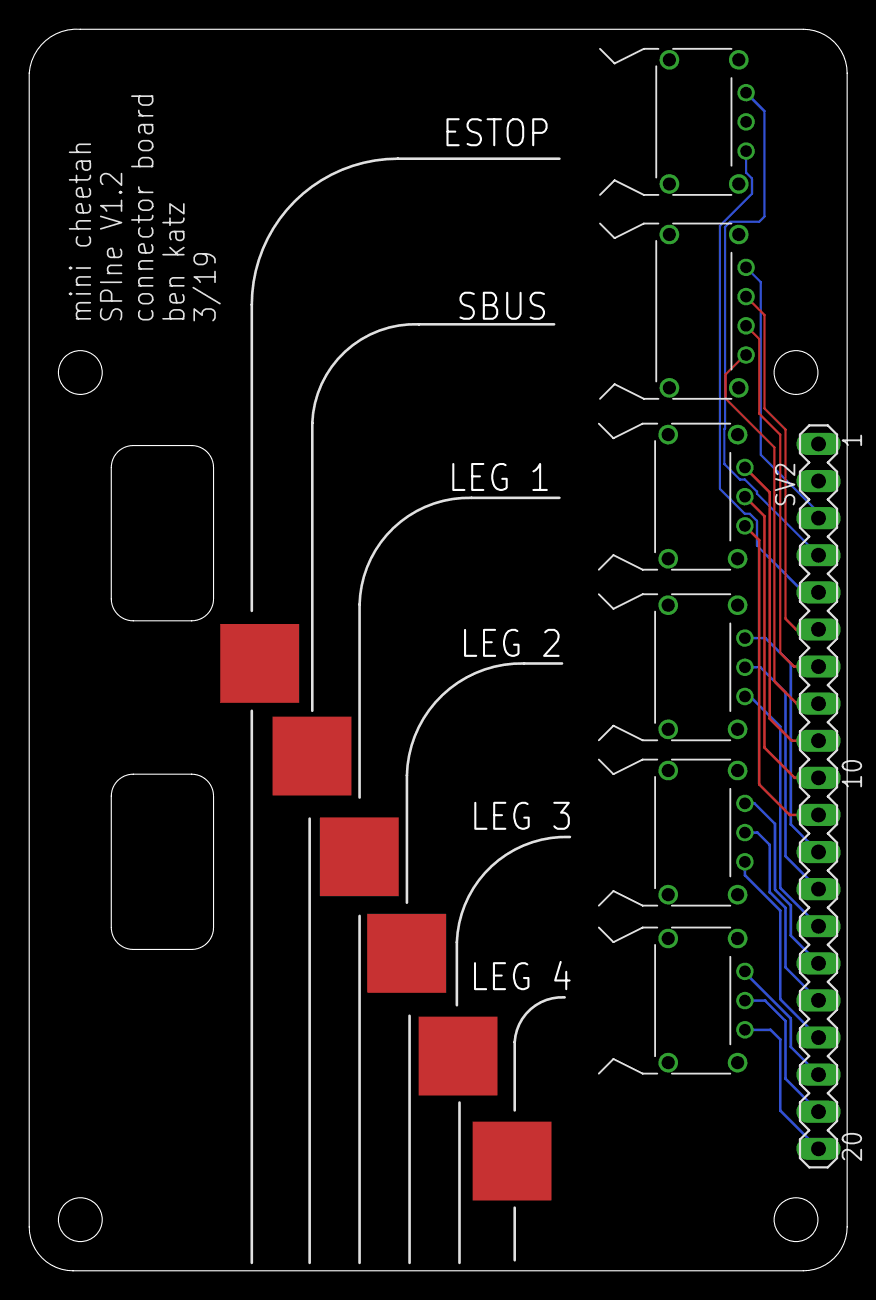
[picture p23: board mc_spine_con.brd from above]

Board: 2 copper layers, 56.0 x 85.0 mm, 14 parts (0 on the bottom side), 17 nets.

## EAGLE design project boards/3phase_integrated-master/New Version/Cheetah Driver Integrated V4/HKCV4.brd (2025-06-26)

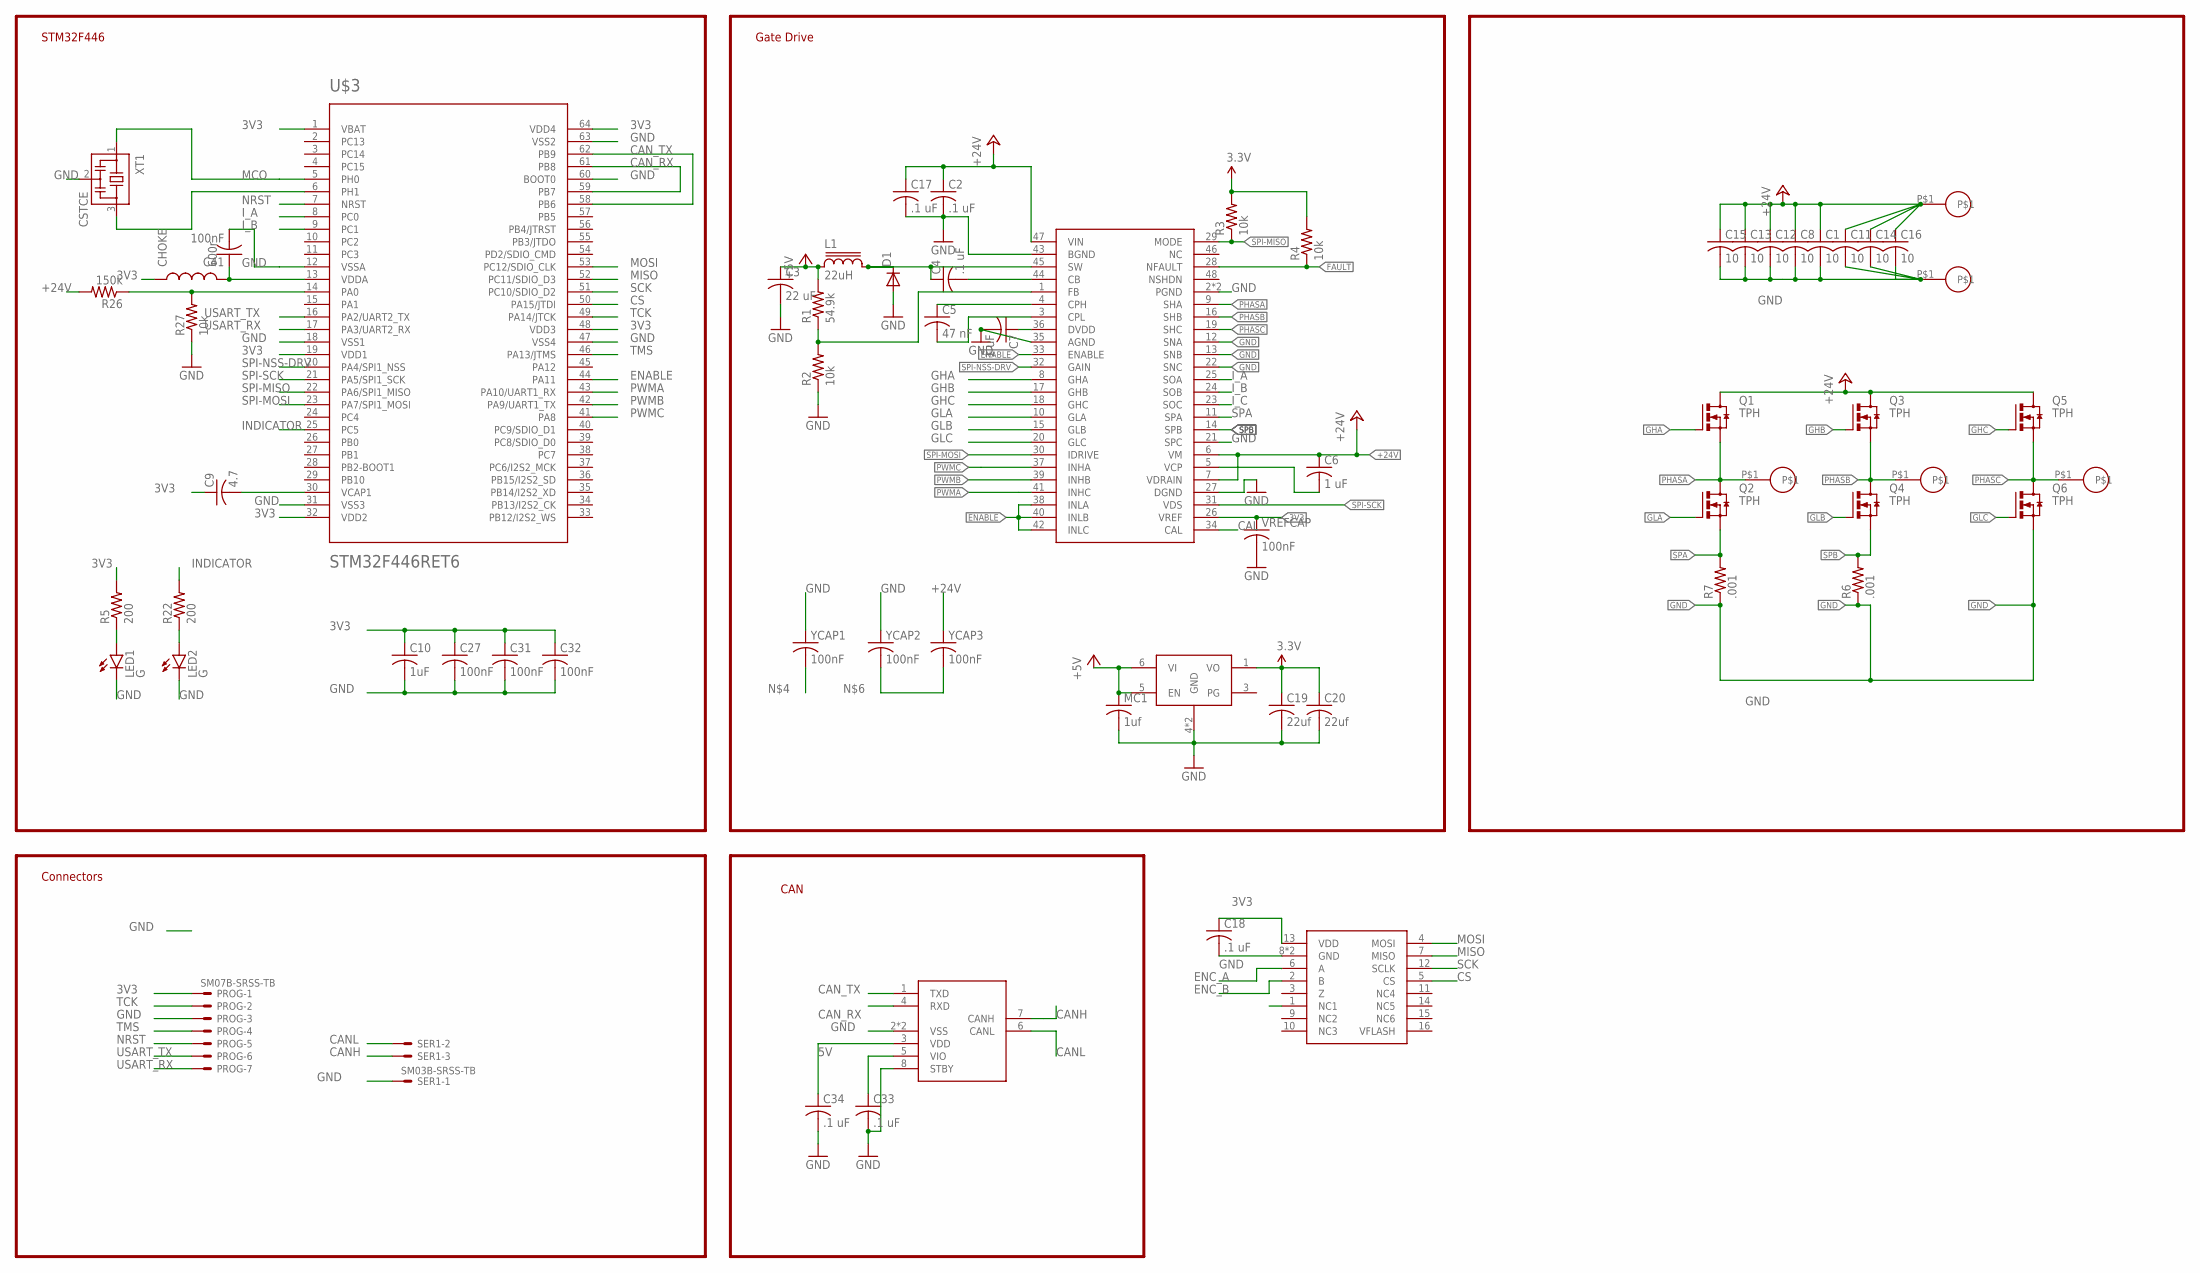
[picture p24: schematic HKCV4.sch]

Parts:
C1, C8, C11, C12, C13, C14, C15, C16: 10; C1206K
C2, C4: .1 uF; C0603K
C3: 22 uF; C0603K
C5: 47 nF; C0402K
C6: 1 uF; C0603K
C7: 1 uF; C0402K
C9: 4.7; C0402K
C10: 1uF; C0402K
C17: .1 uF; C1206K
C18, C33, C34: .1 uF; C0402K
C19, C20: 22uf; C0603K
C27, C31, C32: 100nF; C0402K
C41: 100nF; C0402
CHOKE: 600r; 0603
D1: DIODE-SOD123; SOD123
L1: 22uH; SDR0302
LED1, LED2: G; LED-0603
MC1: 1uf; C0402
PROG: SM07B-SRSS-TB
Q1, Q2, Q3, Q4, Q5, Q6: TPH; TRANS_TPH5900CNH,L1Q
R1: 54.9k; R0402
R2, R3, R4, R27: 10k; R0402
R5, R22: 200; R0402
R6, R7: .001; R1210
R26: 150k; R0402
SER1: SM03B-SRSS-TB
U$1: DRV8323RH; QFN50P700X700X90-49N
U$2, U$4, U$5, U$8, U$10: 18_AWG_PAD
U$3: STM32F446RET6; TQFP64
U$6: MCP2542; TDFN
U$7: LDFM; DFN6-3X3
U$11: MA700; QFN16
VREFCAP: 100nF; C0402K
XT1: CSTCE
YCAP1, YCAP2, YCAP3: 100nF; C0402K

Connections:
3V3: C9.1, C10.1, C18.1, C19.1, C20.1, C27.1, C31.1, C32.1, C33.1, CHOKE.1, PROG.1, R3.2, R4.2, R5.2, U$1.26 (VREF), U$3.1 (VBAT), U$3.19 (VDD1), U$3.32 (VDD2), U$3.48 (VDD3), U$3.64 (VDD4), U$6.5 (VIO), U$7.1 (VO), U$11.13 (VDD), VREFCAP.1
5V: C3.1, C34.1, L1.1, MC1.1, R1.2, U$6.3 (VDD), U$7.5 (EN), U$7.6 (VI)
+24V: C1.1, C2.1, C6.1, C8.1, C11.1, C12.1, C13.1, C14.1, C15.1, C16.1, C17.1, Q1.5 (D), Q1.6 (D), Q1.7 (D), Q1.8 (D), Q1.EP (D), Q3.5 (D), Q3.6 (D), Q3.7 (D), Q3.8 (D), Q3.EP (D), Q5.5 (D), Q5.6 (D), Q5.7 (D), Q5.8 (D), Q5.EP (D), R26.2, U$1.6 (VM), U$1.7 (VDRAIN), U$1.47 (VIN), U$8.P$1, YCAP3.1
BOOT: C4.2, U$1.44 (CB)
CAL: U$1.34 (CAL)
CANH: SER1.3, U$6.7 (CANH)
CANL: SER1.2, U$6.6 (CANL)
CAN_RX: U$3.59 (PB7), U$3.61 (PB8), U$6.4 (RXD)
CAN_TX: U$3.58 (PB6), U$3.62 (PB9), U$6.1 (TXD)
CPH: C5.1, U$1.4 (CPH)
CPL: C5.2, U$1.3 (CPL)
CS: U$3.50 (PA15/JTDI), U$11.5 (CS)
DEVICE3.3: C7.1, U$1.36 (DVDD)
ENABLE: U$1.33 (ENABLE), U$1.38 (INLA), U$1.40 (INLB), U$1.42 (INLC), U$3.44 (PA11)
ENC_A: U$11.6 (A)
ENC_B: U$11.2 (B)
FAULT: R4.1, U$1.28 (NFAULT)
FB: R1.1, R2.2, U$1.1 (FB)
GHA: Q1.4 (G), U$1.8 (GHA)
GHB: Q3.4 (G), U$1.17 (GHB)
GHC: Q5.4 (G), U$1.18 (GHC)
GLA: Q2.4 (G), U$1.10 (GLA)
GLB: Q4.4 (G), U$1.15 (GLB)
GLC: Q6.4 (G), U$1.20 (GLC)
GND: C1.2, C2.2, C3.2, C7.2, C8.2, C10.2, C11.2, C12.2, C13.2, C14.2, C15.2, C16.2, C17.2, C18.2, C19.2, C20.2, C27.2, C31.2, C32.2, C33.2, C34.2, C41.2, D1.A, LED1.C, LED2.C, MC1.2, PROG.3, Q6.1 (S), Q6.2 (S), Q6.3 (S), R2.1, R6.1, R7.1, R27.1, SER1.1, U$1.2 (PGND), U$1.12 (SNA), U$1.13 (SNB), U$1.21 (SPC), U$1.22 (SNC), U$1.27 (DGND), U$1.35 (AGND), U$1.43 (BGND), U$1.49 (PGND), U$3.12 (VSSA), U$3.18 (VSS1), U$3.31 (VSS3), U$3.47 (VSS4), U$3.60 (BOOT0), U$3.63 (VSS2), U$6.2 (VSS), U$6.8 (STBY), U$6.9 (VSS), U$7.4 (GND), U$7.EXP (GND), U$10.P$1, U$11.8 (GND), U$11.TH (GND), VREFCAP.2, XT1.2, YCAP1.1, YCAP2.1
INDICATOR: R22.2, U$3.25 (PC5)
I_A: U$1.25 (SOA), U$3.8 (PC0)
I_B: U$1.24 (SOB), U$3.9 (PC1)
I_C: U$1.23 (SOC)
MCO: U$3.5 (PH0), XT1.1
MISO: U$3.52 (PC11/SDIO_D3), U$11.7 (MISO)
MOSI: U$3.53 (PC12/SDIO_CLK), U$11.4 (MOSI)
unnamed: LED1.A, R5.1
unnamed: C41.1, CHOKE.2, U$3.13 (VDDA)
unnamed: C9.2, U$3.30 (VCAP1)
unnamed: YCAP2.2, YCAP3.2
unnamed: R26.1, R27.2, U$3.14 (PA0)
unnamed: LED2.A, R22.1
unnamed: U$3.6 (PH1), XT1.3
NRST: PROG.5, U$3.7 (NRST)
PHASA: Q1.1 (S), Q1.2 (S), Q1.3 (S), Q2.5 (D), Q2.6 (D), Q2.7 (D), Q2.8 (D), Q2.EP (D), U$1.9 (SHA), U$4.P$1
PHASB: Q3.1 (S), Q3.2 (S), Q3.3 (S), Q4.5 (D), Q4.6 (D), Q4.7 (D), Q4.8 (D), Q4.EP (D), U$1.16 (SHB), U$2.P$1
PHASC: Q5.1 (S), Q5.2 (S), Q5.3 (S), Q6.5 (D), Q6.6 (D), Q6.7 (D), Q6.8 (D), Q6.EP (D), U$1.19 (SHC), U$5.P$1
PWMA: U$1.41 (INHC), U$3.43 (PA10/UART1_RX)
PWMB: U$1.39 (INHB), U$3.42 (PA9/UART1_TX)
PWMC: U$1.37 (INHA), U$3.41 (PA8)
SCK: U$3.51 (PC10/SDIO_D2), U$11.12 (SCLK)
SPA: Q2.1 (S), Q2.2 (S), Q2.3 (S), R7.2, U$1.11 (SPA)
SPB: Q4.1 (S), Q4.2 (S), Q4.3 (S), R6.2, U$1.14 (SPB)
SPI-MISO: R3.1, U$1.29 (MODE), U$3.22 (PA6/SPI1_MISO)
SPI-MOSI: U$1.30 (IDRIVE), U$3.23 (PA7/SPI1_MOSI)
SPI-NSS-DRV: U$1.32 (GAIN), U$3.20 (PA4/SPI1_NSS)
SPI-SCK: U$1.31 (VDS), U$3.21 (PA5/SPI1_SCK)
SW: C4.1, D1.C, L1.2, U$1.45 (SW)
TCK: PROG.2, U$3.49 (PA14/JTCK)
TMS: PROG.4, U$3.46 (PA13/JTMS)
USART_RX: PROG.7, U$3.17 (PA3/UART2_RX)
USART_TX: PROG.6, U$3.16 (PA2/UART2_TX)
VCP: C6.2, U$1.5 (VCP)

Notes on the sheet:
Gate Drive
STM32F446
CAN
Connectors

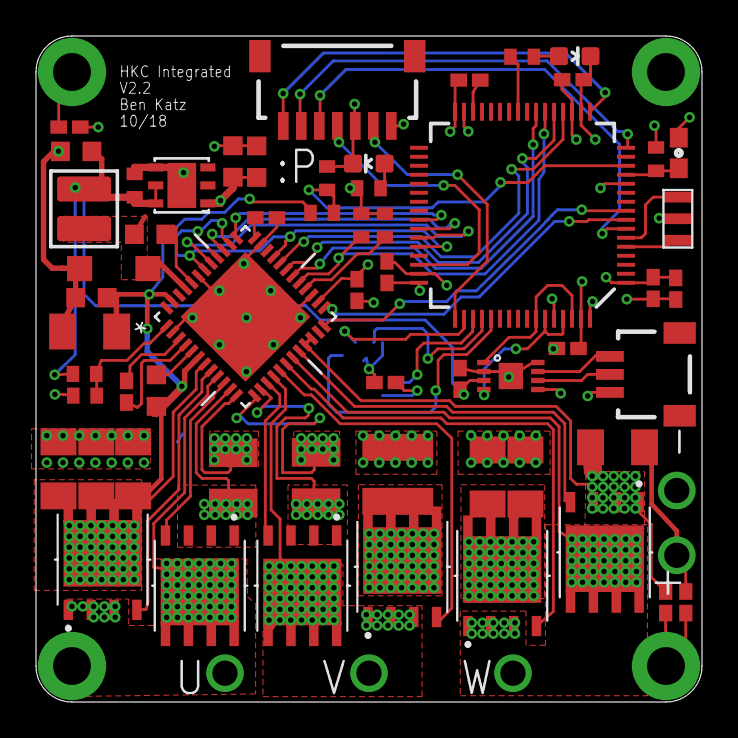
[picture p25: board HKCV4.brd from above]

Board: 4 copper layers, 37.0 x 37.0 mm, 65 parts (1 on the bottom side), 55 nets.

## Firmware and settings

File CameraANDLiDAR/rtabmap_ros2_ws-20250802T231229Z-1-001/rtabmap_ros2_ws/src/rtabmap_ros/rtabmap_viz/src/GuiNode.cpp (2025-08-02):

/*
Copyright (c) 2010-2016, Mathieu Labbe - IntRoLab - Universite de Sherbrooke
All rights reserved.

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
THIS SOFTWARE IS PROVIDED BY THE COPYRIGHT HOLDERS AND CONTRIBUTORS "AS IS" AND
ANY EXPRESS OR IMPLIED WARRANTIES, INCLUDING, BUT NOT LIMITED TO, THE IMPLIED
WARRANTIES OF MERCHANTABILITY AND FITNESS FOR A PARTICULAR PURPOSE ARE
DISCLAIMED. IN NO EVENT SHALL THE COPYRIGHT HOLDER OR CONTRIBUTORS BE LIABLE FOR ANY
DIRECT, INDIRECT, INCIDENTAL, SPECIAL, EXEMPLARY, OR CONSEQUENTIAL DAMAGES
(INCLUDING, BUT NOT LIMITED TO, PROCUREMENT OF SUBSTITUTE GOODS OR SERVICES;
LOSS OF USE, DATA, OR PROFITS; OR BUSINESS INTERRUPTION) HOWEVER CAUSED AND
ON ANY THEORY OF LIABILITY, WHETHER IN CONTRACT, STRICT LIABILITY, OR TORT
(INCLUDING NEGLIGENCE OR OTHERWISE) ARISING IN ANY WAY OUT OF THE USE OF THIS
SOFTWARE, EVEN IF ADVISED OF THE POSSIBILITY OF SUCH DAMAGE.
*/

#include "rtabmap_viz/GuiWrapper.h"
#include "rtabmap/utilite/ULogger.h"

#include <QApplication>
#include <rtabmap/gui/MainWindow.h>
#include <rtabmap/utilite/ULogger.h>
#include <signal.h>

QApplication * app = 0;

void my_handler(int){
	UINFO("rtabmap_viz: ctrl-c catched! Exiting Qt app...");
	app->exit(-1);
}

int main(int argc, char** argv)
{
	UINFO("Starting node...");

	ULogger::setType(ULogger::kTypeConsole);
	ULogger::setLevel(ULogger::kWarning);

	rclcpp::init(argc, argv);

	app = new QApplication(argc, argv);
	app->connect( app, SIGNAL( lastWindowClosed() ), app, SLOT( quit() ) );

	std::vector<std::string> arguments;
	for(int i=1;i<argc;++i)
	{
		arguments.push_back(argv[i]);
	}

	int r;
	{
		rclcpp::NodeOptions options;
		options.arguments(arguments);
		auto node = std::make_shared<rtabmap_viz::GuiWrapper>(options);

		// Catch ctrl-c to close the gui
		// (Place this after QApplication's constructor)
		struct sigaction sigIntHandler;
		sigIntHandler.sa_handler = my_handler;
		sigemptyset(&sigIntHandler.sa_mask);
		sigIntHandler.sa_flags = 0;
		sigaction(SIGINT, &sigIntHandler, NULL);

		// Here start the ROS events loop
		rclcpp::executors::SingleThreadedExecutor executor; //Use 1 thread
		executor.add_node(node);
		auto spin_executor = [&executor]() {
			executor.spin();
		  };

		// Launch executer
		std::thread execution_thread(spin_executor);

		RCLCPP_INFO(node->get_logger(), "rtabmap_viz started.");
		// Now wait for application to finish
		r = app->exec();// MUST be called by the Main Thread

		RCLCPP_INFO(node->get_logger(), "rtabmap_viz stopping spinner...");
		rclcpp::shutdown();
		execution_thread.join();

		RCLCPP_INFO(node->get_logger(), "rtabmap_viz: All done! Closing...");
	}
	delete app;

	return r;
}

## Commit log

2025-06-26 first push
    [BOM.xlsx, HKCV4.brd, HKCV4.sch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]
2025-06-27 second push
    [HKCV4.PrjPcb, HKCV4.SchDoc, mc_spine_con.PrjPcb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]
2025-06-27 Imported Libraries and Projects for Boards
    [74xx-little-us.Library.PrjPcb, 74xx-little-us.PCBLIB, Ben_Library.Library.PrjPcb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]
2025-06-30 new integrated library
    [PDB_Project_4.PrjPcb, PcbLib1.PcbLib, Schlib1.SchLib]
2025-07-01 deleted old files
    [PDB_Project_4.PrjPcb, PcbLib1.PcbLib, Schlib1.SchLib]
2025-07-01 first new spine push
    [Isolated_CAN_Interfaces.SchDoc, Microcontrollers.SchDoc, PCB2.PcbDoc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]
2025-07-14 minimal errors for SPINE board (probably ignorable) need to check connector board but after that we can order Board from OSH Park and then order components
    [74xx-little-us.Library.PrjPcb, 74xx-little-us.PCBLIB, BOM.xlsx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]
2025-07-15 ready to make SPINE Board and SPINE Connector Board
    [spine.PcbDoc]
2025-07-15 Added V2 board files and made initial changes
    [74xx-little-us.Library.PrjPcb, 74xx-little-us.PCBLIB, BOM.xlsx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]
2025-07-15 push for now
    [spine.brd, spine.sch]
2025-07-15 added connector
    [74xx-little-us.Library.PrjPcb, 74xx-little-us.PCBLIB, BOM.xlsx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]
2025-07-17 PDB Board Added
    [BOM.xlsx, mc_psu_v2.brd, mc_psu_v2.sch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]
2025-07-17 First Import from Wizard
    [mc_psu_v2.PcbDoc, mc_psu_v2.PrjPcb, mc_psu_v2.SchDoc]
2025-07-17 Lab Rules SPINE
    [mc_psu_v2.PcbDoc, spine.PcbDoc]
2025-07-17 resized + Carvera Setting Board
    [spine.PcbDoc]
2025-07-21 width adjustments 1
    [spine.PcbDoc]
2025-07-21 vias are under components
    [spine.PcbDoc]
2025-07-21 Changed trace width
    [spine.PcbDoc]
2025-07-22 Old SPINE Board added
    [BOM.xlsx, mc_spine_con.PcbDoc, mc_spine_con.PrjPcb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]
2025-07-22 straight races for connector board
2025-07-22 better formatting for Connector
2025-07-22 added parts
    [spine.PcbDoc]
2025-07-23 added smaller SPIne Board
    [74xx-little-us.PCBLIB, BOM.xlsx, Ben_Library.PCBLIB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]
2025-07-23 added schematic
    [mc_spine_con.sch]
2025-07-23 Smaller Board Size
    [mc_spine_con.PrjPcb]
2025-07-24 added lidar connection lib
    [2.1mm LiDAR power surface mount plug.stp, FC68148S.PcbLib, FC68148S.SchLib]
2025-07-24 added 2.1mm plug to schematic
    [mc_psu_v2.SchDoc]
2025-07-24 added 2.1mm plug to pcb
    [FC68148S.PcbLib, mc_psu_v2.PcbDoc, mc_psu_v2.SchDoc]
2025-07-24 added footprint to pcb
    [FC68148S.PcbLib, mc_psu_v2.PcbDoc]
2025-07-24 added connections and final revisions
    [mc_psu_v2.PcbDoc, mc_psu_v2.PrjPcb]
2025-07-25 first forund of OSH park rules still some errors to fix
    [mc_psu_v2.PcbDoc, mc_psu_v2.PrjPcb, spine_v2_smaller.PcbDoc]
2025-07-28 fixed all rules
    [spine_v2_smaller.PcbDoc]
2025-07-28 Gerber Files Added
    [spine_v2_smaller.GBL, spine_v2_smaller.GBO, spine_v2_smaller.GBP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]
2025-07-28 new gerber
    [spine_v2_smaller.GBL, spine_v2_smaller.GBO, spine_v2_smaller.GBP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]
2025-07-28 Correct gerber files
2025-07-29 removing comm board july created file
2025-07-29 Added Adjustment BOM
    [Adjusted BOM SPINE.xlsx]
2025-07-29 docs: Add README for smaller SPIne board
2025-07-31 Resolved merge conflict and committed local changes
    [loading Ethan.SchDoc, mc_spine_con.PrjPcb, spine.PrjPcb]
2025-07-31 added gerber files and settings
    [July31SPIne.PrjPcb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]
2025-07-31 better SPIne Folder Added
    [74xx-little-us.PCBLIB, BOM.xlsx, Ben_Library.PCBLIB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]
2025-07-31 shorter names
    [2.1mm LiDAR power surface mount plug.stp, BOM.xlsx, FC68148S.PcbLib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]
2025-07-31 more changes
    [LiDAR power surface mount plug.stp]
2025-07-31 added lidar + camera
    [D415.obj, D435.obj, D455.obj]
2025-08-01 Remove LiDAR + Camera Vision & Nav folder
    [D415.obj, D435.obj, D455.obj]
2025-08-01 deleted old pdb docs and added new ones
    [HKCV4.PrjPcb, PDB_v1.PcbDoc, PDB_v1.PrjPcb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]
2025-08-01 deleted old boards folder
    [2.1mm LiDAR power surface mount plug.stp, BOM.xlsx, FC68148S.PcbLib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]
2025-08-01 added fuse to pcb
    [PDB_v1.PcbDoc, PDB_v1.SchDoc]
2025-08-01 final summer revision, PDB is done and ready to order after peer review
    [PDB_v1.PcbDoc]
2025-08-01 new final revision, replace 5v converter to give 6A
    [PDB_v1.PcbDoc]
2025-08-01 5v out from 5v converter trace width increased to be 150mil for 6A
    [PDB_v1.PcbDoc]
2025-08-02 refactor: Move sensor workspaces into CameraANDLiDAR folder
2025-08-02 feat: Add RTAB-Map workspace and project files
    [D415.obj, D435.obj, D455.obj]
2025-09-06 deleted copper pour
    [spine.PcbDoc]

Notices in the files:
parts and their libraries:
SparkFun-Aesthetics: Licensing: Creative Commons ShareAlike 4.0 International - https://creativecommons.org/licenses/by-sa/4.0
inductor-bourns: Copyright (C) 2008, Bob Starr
